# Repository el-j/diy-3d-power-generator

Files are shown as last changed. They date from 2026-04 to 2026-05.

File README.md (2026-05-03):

<p align="center">
  
  
  
  
</p>

<h1 align="center">🌬️ WindPower-3D</h1>
<h3 align="center">Open-Source Helix Helix Wind Generator — Fully 3D Printable</h3>

<p align="center">
  <strong>Parametric • Modular • AI-Orchestrated Design Bureau</strong><br/>
  Erzeuge deinen eigenen Strom mit einem 3D-gedruckten Windgenerator.<br/>
  <em>Generate your own power with a fully 3D-printed wind generator.</em>
</p>

---

## ⚡ Was ist WindPower-3D?

Ein **vollständig 3D-druckbarer Helix-Helix Windgenerator** mit integriertem XXL Axialfluss-Generator. Designed für den Bambu Lab P1S (256×256mm), aber kompatibel mit jedem FDM-Drucker.

### 🌟 Features

| Feature | Details |
|---|---|
| 🔄 **Modularer Turm** | Stapelbare Helix-Etagen mit 12-Zahn Vielzahn-Kupplung |
| ⚡ **XXL Generator** | 180mm Rotoren, 20-Pol, ovale Capsule-Spulen (40×26mm!) |
| 🏗️ **XXL Basis-Station** | 220mm Ø, Stacking-Deckel, Wartungsklappe, wasserdichte Bodenwanne |
| 🔧 **Profi-Werkzeuge** | Traversier-Wickelmaschine, Magnet-Puffer, Akkuschrauber-Aufsatz |
| 📐 **Parametrisches Design** | Alle Maße in JSON — ändere eine Zahl, alles passt sich an |
| 🤖 **AI Design Bureau** | 7 spezialisierte Agenten orchestrieren den Konstruktions-Workflow |
| 📋 **Lebende BOM** | Stückliste aktualisiert sich automatisch bei Änderungen |
| 📖 **Bauanleitungen** | Schritt-für-Schritt auf Deutsch mit Sicherheitshinweisen |

---

## 🏗️ System-Architektur

```mermaid
graph LR
    subgraph "🌬️ Wind Turbine"
        T["🗼 Helix Tower\n(Modular Stages)"]
        G["⚡ Generator\n(Axial Flux)"]
        B["🏗️ Base Station\n(Tree Mount)"]
    end
    
    subgraph "🤖 AI Design Bureau"
        O["🎛️ Orchestrator"]
        CAD["📐 CAD Engineer"]
        DRW["📏 Drawing Agent"]
        COD["🐍 FreeCAD Coder"]
        BOM["📋 BOM Manager"]
        BGD["📖 Build Guide"]
        QA["✅ QA Inspector"]
    end
    
    T --> G --> B
    O --> CAD --> DRW --> COD --> BOM --> BGD --> QA
    QA -->|PASS| O
```

---

## 📦 Baugruppen / Assemblies

### 🗼 Helix-Turm
Modulares Stecksystem mit 12-Zahn Vielzahn-Kupplung. Jede Etage: 2 Helix-Flügel (90° Twist), 1 Skelett-Verbinder, 1 Achsen-Plug.

### ⚡ XXL Axialfluss-Generator *(NEU v2!)*
Sandwich-Bauweise mit **180mm Rotoren** und **ovalen Capsule-Spulen** (40×26mm statt runde Ø14mm). 20 Neodym-Magnete auf R74mm Kreis für massives Drehmoment. Leichtbau-Skelettierung für weniger Filament und bessere Kühlung.

### 🏗️ XXL Basis-Station *(NEU v2!)*
**220mm Ø Gehäuse** mit 50mm Kegelrollenlager (real gemessen!), Stacking-Deckel, 3× Wand-Flansche, wasserdichte Bodenwanne und Elektronik-Wartungsklappe mit Backpack-Gehäuse.

### 🔧 Werkzeuge *(Erweitert v2!)*
- **Easy-Tool**: Akkuschrauber-Aufsatz zum schnellen Spulenwickeln
- **Komplex-Spooler**: Professionelle Traversier-Wickelmaschine (1:24 Zahnrad-Untersetzung, 4 Achsen, Skeleton-Basis)
- **Magnet-Puffer**: Magnetischer Drahtspanner mit T-Nut-Schiene und Filz-Bremse

---

## 🚀 Quick Start

### 1. Repository klonen
```bash
git clone https://github.com/YOUR_USERNAME/windpower-3d.git
cd windpower-3d
```

### 2. Stückliste prüfen
→ [`docs/bom/master_bom.md`](docs/bom/master_bom.md) — Alle Druck- und Kaufteile

### 3. Drucken
Öffne die STL-Dateien aus `exports/` in deinem Slicer. Empfohlenes Material: **PETG**.

### 4. Bauen
→ [`docs/build-guide/`](docs/build-guide/README.md) — Schritt-für-Schritt Anleitungen

### 5. FreeCAD Scripts laden (optional)
```python
# In FreeCAD Python Console einmal pasten:
exec(open("windpower-3d/freecad_loader.py").read())

# Dann jedes Script laden:
run("bigBasis/big_base_station")       # XXL Basis
run("bigBasis/big_base_generator")      # XXL Generator
run("Helix_Leaf+Connector")             # Turm
run("tools/komplexSPooler/Traversier-Basis & Skeleton")  # Wickelmaschine
```

### 6. Landing Page (TypeScript + Vite)
```bash
npm install
npm run typecheck
npm run dev
```

Production build:
```bash
npm run build
```
Das Ergebnis liegt in `dist/` und wird von GitHub Pages deployed.

### 7. GitHub Actions CI/CD (Static Hosting)
- CI Workflow: `.github/workflows/ci.yml` (führt `npm ci`, `npm run typecheck`, `npm run build` aus)
- Pages Deploy: `.github/workflows/deploy-pages.yml` (baut Artifact und deployed nach GitHub Pages)

Wichtig in GitHub Repo Settings:
- `Settings > Pages > Build and deployment` auf **GitHub Actions** setzen

---

## 📋 Stückliste (Kurzfassung)

| Kategorie | Menge (XXL, 3 Etagen) |
|---|:---:|
| 🖨️ Druckteile (Hauptanlage) | 29 Stück |
| 🖨️ Druckteile (Werkzeuge) | 3–22 Stück |
| 🔩 Einschmelzmuttern + Schrauben | ~52 Stück |
| 🧲 Neodym-Magnete (20×5×3mm) | **40 Stück** |
| ⚙️ Kegelrollenlager (29×50×15) | 1 Stück |
| 📏 Vierkant-Achse (10×10mm) | 1 Stück |
| 🔌 Kupferlackdraht (Ø0.5mm) | ~100m |
| 📦 Geschätztes Filament | ~1.5kg PETG |

→ [**Vollständige Stückliste**](docs/bom/master_bom.md)

---

## 🤖 AI Design Bureau

Dieses Projekt nutzt ein **KI-Agenten-System** inspiriert von [agency-agents](https://github.com/msitarzewski/agency-agents) und [claude-agent-blueprint](https://github.com/mongoistkeingemuese/claude-agent-blueprint).

### 7 Spezialisierte Agenten

| Agent | Aufgabe |
|---|---|
| 🎛️ **Orchestrator** | Pipeline-Management, Quality Gates, Retry-Logik |
| 📐 **CAD Engineer** | Parametrisches Design, Toleranzen, Druckbarkeit |
| 📏 **Drawing Agent** | 3-Ansichten-Zeichnungen (Front, Seite, Draufsicht) |
| 🐍 **FreeCAD Coder** | Python-Scripts, STL-Export, parametrische Geometrie |
| 📋 **BOM Manager** | Stückliste pflegen (JSON + Markdown) |
| 📖 **Build Guide Author** | Bauanleitungen auf Deutsch |
| ✅ **QA Inspector** | Vollständigkeits- und Konsistenzprüfung |

### Design-Pipeline

```
📐 Design → 📏 3-Ansichten → 🐍 FreeCAD Code → 📋 BOM Update → 📖 Bauanleitung → ✅ QA
     ↑                                                                                  │
     └──────────────────────── Feedback bei FAIL ──────────────────────────────────────┘
```

→ [**Architektur-Details**](docs/ARCHITECTURE.md)

---

## 📂 Projektstruktur

```
windpower-3d/
├── .agents/                    # 🤖 AI Agent System
│   ├── identities/             #    7 Agenten-Identitäten
│   ├── workflows/              #    Pipeline-Definitionen (JSON)
│   └── state.json              #    Orchestrator-Status
├── assemblies/                 # 📦 Baugruppen-Metadaten
│   ├── tower/                  #    🗼 Helix-Turm
│   ├── xl-base-station/        #    🏗️ XXL Basis-Station (AKTIV)
│   ├── xl-generator/           #    ⚡ XXL Generator (AKTIV)
│   ├── base-station/           #    📦 Legacy Kleine Basis
│   ├── generator/              #    📦 Legacy Generator
│   └── tools/                  #    🔧 4× Werkzeug-Sets
├── shared/                     # 🔗 Geteilte Ressourcen
│   ├── parameters.json         #    Zentrale Parameter-Registry (v2)
│   ├── freecad_utils.py        #    FreeCAD Utilities (inkl. Capsule!)
│   ├── materials.json          #    Material-Definitionen
│   └── fasteners.json          #    Verbindungselemente-Katalog
├── src/                        # 💻 FreeCAD Scripts
│   ├── bigBasis/               #    🏗️ XXL Basis + Generator
│   ├── smalBasis/              #    📦 Legacy (kleine Variante)
│   ├── tools/                  #    🔧 Werkzeuge
│   │   ├── komplexSPooler/     #       Traversier-Wickelmaschine
│   │   ├── firstSpooler/       #       Original-Wickler
│   │   ├── magnetPuffer/       #       Drahtspanner
│   │   └── easy_tool_*         #       Akkuschrauber-Aufsatz
│   └── Helix_Leaf+Connector.py #    🗼 Turm-Flügel
├── exports/                    # 📤 STL/3MF Exporte
├── freecad_loader.py           # 🚀 FreeCAD Script-Loader
├── docs/                       # 📚 Dokumentation
└── README.md                   #    ← Du bist hier
```

---

## 🛠️ Für Entwickler / FreeCAD Anpassungen

### Parameter ändern
Alle Maße sind zentral in [`shared/parameters.json`](shared/parameters.json) definiert:

```json
{
  "tower": {
    "blatt_radius": { "value": 66.0, "unit": "mm", "desc": "Helix-Blatt Radius" },
    "twist_winkel": { "value": 90.0, "unit": "deg", "desc": "Helix-Drehwinkel" }
  }
}
```

### Utility-Funktionen
[`shared/freecad_utils.py`](shared/freecad_utils.py) enthält alle gemeinsam genutzten Funktionen:
- `make_square_prism()` — Vierkant-Achsloch
- `make_vielzahn_prism()` — 12-Zahn Kupplung
- `make_capsule()` — Ovale Spulen-Form *(NEU v2)*
- `make_centered_box()` — Zentrierter Quader *(NEU v2)*
- `create_capsule_array()` — Kreisförmige Capsule-Muster *(NEU v2)*
- `create_circular_array()` — Kreisförmige Zylinder-Muster
- `load_parameters()` — Parameter aus JSON laden

---

## 🤝 Mitmachen / Contributing

Wir freuen uns über Beiträge! Siehe [`CONTRIBUTING.md`](CONTRIBUTING.md) für Details.

### Möglichkeiten
- 🐛 **Bugs melden** — Toleranzen, Passungsprobleme, Druckfehler
- 📐 **Design verbessern** — Neue Varianten, bessere Geometrie
- 📖 **Dokumentation** — Bauanleitungen, Übersetzungen
- 🤖 **Agenten** — Neue Fähigkeiten, bessere Learnings
- 🌍 **Übersetzungen** — Build-Guide in andere Sprachen

---

## 📜 Lizenz

MIT License — siehe [LICENSE](LICENSE)

---

<p align="center">
  <strong>🌬️ Erzeuge deinen eigenen Strom. Open Source. Druckbar. Modular.</strong><br/>
  <em>Made with ❤️ and a lot of PETG</em>
</p>

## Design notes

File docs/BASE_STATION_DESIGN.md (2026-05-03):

# XXL Base Station Design Reference

**Assembly**: XL Base Station v3.0  
**Source**: `src/base/helix_station.py`  
**Status**: ACTIVE

---

## Design Philosophy

The XXL Base Station solves a deceptively difficult mechanical problem: house a spinning shaft, two tapered roller bearings, a removable stator, a rectifier PCB, and wall-mounting hardware — all in a weatherproof enclosure that fits on a 256×256 mm print bed and does not look like an industrial accident bolted to a wall.

The guiding constraint was radical flatness. Earlier prototypes ran 120 mm tall. The current design is **68 mm** — a 43% reduction achieved by rethinking where the bearing stack sits relative to the stator and by eliminating an internal electronics bay in favour of a front-access service hatch. The result is a low-profile disc that presents minimal wind resistance on its mounting surface and routes cables cleanly through a single port at the base of the hatch.

Serviceability drove the second major decision: the stator must be removable without disturbing the rotor or bearings. Rewinding a stator coil after a fault is a routine maintenance event. Requiring a full teardown for that task is unacceptable in a field-mounted turbine. The solution is a precision U-form opening in the front face that lets the 9 mm stator slide in and out laterally — bearings stay in place, rotor stays in place, downtime is minutes rather than hours.

---

## Key Innovations

### Ultra-Flat 68 mm Profile

Outer diameter is 220 mm (R=110 mm) and total height is 68 mm. The inner chamber runs to R=96 mm, giving exactly 4 mm radial clearance to the rotor at R=92 mm. That clearance is a hard minimum — the rotor must never exceed R=95 mm. The flat profile lowers the aerodynamic shadow behind the mounting surface and simplifies cable exit geometry.

### U-Form Front Opening and Stator Slot

The front face has a full-height U-shaped cutout: 213 mm wide (±106.5 mm from centre), 68 mm tall. This is not a maintenance port — it is a first-class design feature. The stator slides through it horizontally to seat in a precision slot at Z=25.8–35.3 mm. Slot dimensions are 9.5 mm high (9 mm stator + 0.5 mm clearance) at a radius of 99.5 mm. The slot is cut as a 99.5 mm cylindrical channel intersected with a 200×140 mm rectangular box. The service hatch mirrors this with a 199×120 mm passage at the same Z height, so the stator path is clear even with the hatch fitted.

### 3D-Printed Bearing Cup Substitute

Rather than sourcing the metal outer race of the 32005 tapered roller bearing separately, the design includes a printed substitute cup (`Ersatz_Lagerschale_32005`): 50 mm outer diameter, 12 mm tall, with an internal taper from R=19.5 mm at the base to R=23 mm at the top. Only the cup is printed; the roller and cone assembly are standard metal hardware. This removes a sourcing dependency while keeping the load-bearing contact surfaces metal.

---

## Part Reference

| Part ID | FreeCAD Name | Function | Qty |
|---|---|---|---|
| XL-HOUS-01 | `Basis_Gehaeuse_XXL` | Main housing, R=110 mm, H=68 mm | 1 |
| XL-DECK-01 | `Stacking_Lager_Deckel_FLACH` | Top lid with bearing pocket | 1 |
| XL-FLNSH-01 | `Wand_Flansch` | Wall mounting flange | 3 |
| XL-KLAP-01 | `Elektronik_Wartungs_Klappe` | Front service hatch | 1 |
| XL-BODEN-01 | `Wartungsklappen_Boden` | Detachable hatch floor | 1 |
| — | `Ersatz_Lagerschale_32005` | Printed bearing cup substitute | 1 |

### XL-HOUS-01 — Main Housing

Outer radius 110 mm, height 68 mm, inner chamber R=96 mm. U-form opening 213 mm wide × 68 mm tall. Stator slot at Z=25.8 mm, height 9.5 mm, radius 99.5 mm.

### XL-DECK-01 — Stacking Lid

Outer radius 110 mm, height 18 mm. Bearing pocket 50.2 mm diameter × 15 mm deep (32005 bearing). Upper guide lip: R=85–95.5 mm, 6 mm tall, for centering. Six 20 mm weight-relief holes at R=70 mm. Twelve M3 fasteners at R=104 mm, 30° spacing with 15° offset.

### XL-FLNSH-01 — Wall Flange (×3)

L-shaped bracket: vertical face 40×68 mm × 6 mm thick; horizontal arm 50×40 mm × 6 mm thick. Triangular gussets 4.0 mm reinforce the joint. Wall screws: 4× M3 at Z=15 mm and Z=53 mm, Y=±12 mm. Equipment mounting: 2× M6 on arm at Y=±10 mm, 38 mm deep.

### XL-KLAP-01 — Service Hatch

U-shaped, matching 213×150 mm front opening exactly. Wall thickness 6 mm roof and sides. Interior cavity 201×145 mm for PCB and wiring. Four PCB standoffs (4 mm OD, 5 mm tall) at (±25 mm, Z=20 mm) and (±25 mm, Z=50 mm). Cable port 10 mm diameter at X=0, Y=−135 mm, Z=10 mm. Two M3 lock screws at Y=−20 mm, Z=34 mm (left and right faces). Stator slot passage: 199×120 mm at Z=25.8 mm.

### XL-BODEN-01 — Hatch Floor

6 mm thick plate with R=96 mm rotor clearance cutout. Four corner tabs 12×12×8 mm with M3 counterbores for tool-free removal.

---

## Hardware BOM

| Item | Spec | Qty | Notes |
|---|---|---|---|
| Tapered roller bearing | 32005 — 29×50×15 mm | 1 | Dimensions real-measured, not datasheet |
| Hex socket cap screw | M3×10 | 12 | Lid-to-housing |
| Hex socket cap screw | M3×8 | 8 | Hatch lock + floor tabs |
| Hex socket cap screw | M6×40 | 6 | Wall flange equipment bolts (2× per flange) |
| Wood / masonry screw | M4 or M5 | 12 | Wall mounting (4× per flange) |
| Rectifier PCB | — | 1 | Mounts on hatch standoffs |
| Cable gland / sleeve | 10 mm ID | 1 | Hatch cable port |

---

## Print Settings

| Part | Material | Nozzle | Infill | Notes |
|---|---|---|---|---|
| XL-HOUS-01 | PLA-CF | 0.6 mm | 30% | Large print — check bed orientation |
| XL-DECK-01 | PLA-CF | 0.4 mm | 40% | Bearing pocket requires precision |
| XL-FLNSH-01 | PLA-CF | 0.6 mm | 60% | Structural — print all 3 |
| XL-KLAP-01 | PETG | 0.6 mm | 25% | Service part, slight flex acceptable |
| XL-BODEN-01 | PETG | 0.6 mm | 25% | Detachable, does not carry load |

All parts fit within the 256×256×256 mm Bambu P1S envelope. XL-HOUS-01 at 220 mm diameter prints diagonally on the bed. Orient so the U-form opening faces up to avoid internal support in the stator slot cavity.

---

## Critical Dimensions Summary

| Parameter | Value | Constraint |
|---|---|---|
| Outer diameter | 220 mm (R=110) | Print bed diagonal |
| Total height | 68 mm | Flat-profile target |
| Inner chamber | R=96 mm | 4 mm clearance to rotor R=92 |
| U-opening width | 213 mm | Stator insertion path |
| Stator slot Z | 25.8–35.3 mm | Synchronized with hatch |
| Stator slot height | 9.5 mm | 9 mm stator + 0.5 mm clearance |
| Bearing seat | Ø50.2 mm × 15 mm | 32005 press fit |
| Rotor hard limit | R=95 mm max | Geometry enforced in parameters.json |

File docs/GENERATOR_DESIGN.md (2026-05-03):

# Aero-Fan Generator — Design Document

**Project**: WindPower-3D | **Assembly**: XL Generator v3.0 | **Status**: Active

---

## Overview

The Aero-Fan generator is a 3D-printable **axial-flux permanent magnet generator (AFPMG)** designed for small-scale wind power applications. It is built around a TORUS-NS dual-rotor topology and introduces two notable mechanical innovations: a dual-function fan/magnet rotor and a unified spline coupling system that eliminates tool dependencies during blade changes.

---

## Key Innovations

> **Dual-function rotor**: The rotor plates (`XLG-ROT-01`, `XLG-ROT-02`) carry both the permanent magnets and 11 aerodynamic fan blades in a single printed part. As the rotor spins, it simultaneously generates electricity through rotating magnetic fields and forces cooling airflow across the stator coils via centrifugal action — removing the need for a separate cooling fan while keeping the assembly compact.

> **Capsule coils**: The stator (`XLG-STAT-01`) uses oval (stadium-shaped) coil pockets rather than round ones, aligning coil geometry with the arc of the magnet circle (R=74 mm). This reduces end-winding waste and improves copper fill in the radial space available.

> **Unified Vielzahn spline**: Every rotary connection in the system uses the same 12-tooth spline profile — tower blades, generator rotor, and tools all share `r_out=9.0 mm`, `r_in=7.8 mm`, 12 teeth. This gives 30° indexing resolution and enables tool-free hot-swap of components.

---

## Design Philosophy

The generator is sized to fit a 256×256×256 mm Bambu P1S print bed and targets a reliable 10–50 W output range at low wind speeds (6–12 m/s). Every dimensional choice reflects a compromise between magnetic performance and printability:

- **Axial-flux topology** keeps the generator thin and flat — ideal for integration into a vertical tower without adding height.
- **20-pole, 12-coil configuration** (TORUS-NS) gives a 3-phase output at usable frequencies even at low RPM. At 100 RPM the electrical frequency is approximately 33 Hz (`100 RPM × 20 poles / 60`).
- **N52 neodymium magnets** (20×5×3 mm) were chosen as a standard stocked size. The magnet circle radius of R=74 mm also doubles as the rotor fastening radius, reducing the number of unique drill positions.
- **4 mm rotor-to-chamber clearance** (`rotor R=92 mm`, inner chamber `R=96 mm`) is maintained as a hard constraint — the rotor must never exceed R=95 mm.
- **PLA-CF for structural parts**, PETG for the stator: carbon-fiber PLA provides stiffness at the rotor and bearing interfaces; PETG tolerates the heat generated in the stator coils.

---

## How It Works

**Faraday's law** states that a changing magnetic flux through a coil induces a voltage proportional to the rate of change. In an axial-flux machine, the magnets are oriented with their poles facing axially (parallel to the shaft), and the coils sit in a flat disk (the stator) between two rotor plates. As each magnet passes over a coil, the flux through that coil changes sign (N→S polarity), inducing an AC voltage.

The dual-rotor arrangement (one rotor plate above and one below the stator) doubles the flux linkage per coil compared to a single-sided design, increasing output for the same rotor diameter.

The 12 stator coils are wired in a **3-phase star (Y) configuration** with 4 coils per phase. At 100 RPM with 20 pole pairs the phase voltage frequency is `f = n × p / 60 = 100 × 10 / 60 ≈ 16.7 Hz` electrical. The output is rectified to DC for battery charging or direct LED load testing. Design efficiency target is η=72%.

---

## Generator Topology

| Parameter | Value |
|---|---|
| Type | Axial-flux, dual-rotor, single-stator (TORUS-NS) |
| Poles | 20 (10 pole pairs) |
| Coils | 12 capsule-shaped (4 per phase, 3-phase AC) |
| Magnet spec | 20×5×3 mm N52 neodymium |
| Magnet circle radius | R=74 mm (= rotor screw radius) |
| Design output | 10–50 W at 6–12 m/s |
| Efficiency target | η=72% |

---

## The Aero-Fan Rotor (`XLG-ROT-01` / `XLG-ROT-02`)

| Parameter | Value |
|---|---|
| Total radius | 92 mm (Ø184 mm) |
| Hub radius | 16.5 mm |
| Outer structural rim | R=92–102 mm |
| Fan blades | 11 aerodynamic blades (lofted profile) |
| Inner blade profile | R=11.5 mm, chord=22 mm, pitch angle=75° |
| Outer blade profile | R=107 mm, chord=32 mm, pitch angle=50°, sweep=45° |
| Weight-relief pockets | 15 capsule pockets (18×10 mm), avoiding 5 screw positions |
| Fastening | 5× M3 heat-set inserts at R=74 mm: 10°, 82°, 154°, 226°, 298° |
| Magnet lip | 0.6 mm retaining edge per pocket |

The **backplates** (`XLG-BP-01` / `XLG-BP-02`) are thin structural rings (R=62–86 mm, 4 mm height) with synchronized magnet pockets that close the magnet retention from the opposite side.

---

## The Stator (`XLG-STAT-01` / `XLG-STAT-02`)

| Parameter | Value |
|---|---|
| Outer radius | 99 mm |
| Thickness | 9 mm |
| Base bore | R=16 mm (shaft clearance) |
| Coil pocket (outer) | 40.4×26.4 mm (0.4 mm clearance) |
| Coil winding core | 22×8 mm |
| Coil depth | 6 mm |
| Coil count | 12 at R=74 mm |
| Winding | 120–150 turns, 0.5 mm enameled copper wire |
| Weight-relief holes | 6× at R=35 mm |
| Cable channel | Ring channel R=82–88 mm at Z=6.5 mm + radial handle channel |

The stator lid (`XLG-STAT-02`) is a thin cover ring (R=50.5–95.5 mm, 1.5 mm thick) with cutouts matching the coil pockets, allowing wire routing after winding.

---

## Assembly Stack (bottom to top)

| Z position | Part | Part ID |
|---|---|---|
| −80 mm | Bearing reducer (bottom) | `XLG-REDUZ-01` |
| −60 mm | Bearing clamp (bottom, rotated 180°) | `XLG-CLAMP-02` |
| −50 mm | Rotor stack clamp (30 mm plug) | `XLG-CLAMP-01` |
| −30 mm | Backplate (bottom) | `XLG-BP-01` |
| −20 mm | Aero-Fan Rotor (bottom) | `XLG-ROT-01` |
| −5 mm | Stator spacer 10 mm | `XLG-SPACER-01` |
| 0–9 mm | Stator housing | `XLG-STAT-01` |
| 10–25 mm | Stator lid (inset) | `XLG-STAT-02` |
| 35 mm | Aero-Fan Rotor (top) | `XLG-ROT-02` |
| 50 mm | Backplate (top) | `XLG-BP-02` |
| 90 mm | Bearing clamp (top) | `XLG-CLAMP-03` |
| 110 mm | Bearing reducer (top, rotated 180°) | `XLG-REDUZ-02` |

---

## Bearing System

- **Type**: Tapered roller bearing 32005 — 29×50×15 mm (real measured dimensions)
- **Press fit**: 0.15 mm interference fit for shaft coupling
- **Bearing reducer** (`XLG-REDUZ-01` / `XLG-REDUZ-02`): Conical adapter tapering 27.5→29.3 mm over 2 mm taper length, with a 34 mm collar

---

## Vielzahn Coupling System

All rotary connections throughout the system (tower blades, generator rotor, tools) share a single unified spline profile to avoid mismatched parts:

| Parameter | Value |
|---|---|
| Teeth | 12 (30° indexing) |
| Outer radius | 9.0 mm |
| Inner radius | 7.8 mm |
| Orientation offset | +15° (aligns teeth to square shaft corners) |
| Square shaft bore | 10×10 mm + 0.5 mm tolerance |

---

## Print Settings

| Part | Material | Nozzle | Infill | Notes |
|---|---|---|---|---|
| `XLG-ROT-01` / `XLG-ROT-02` | PLA-CF | 0.6 mm | 40% | Carbon fiber for stiffness |
| `XLG-STAT-01` | PETG | 0.6 mm | 30% | Heat-resistant for coil area |
| `XLG-BP-01` / `XLG-BP-02` | PLA-CF | 0.6 mm | 40% | Thin ring, needs strength |
| `XLG-CLAMP-*` | PLA-CF | 0.4 mm | 100% | Bearing contact surface |
| `XLG-REDUZ-*` | PLA-CF | 0.4 mm | 100% | Press-fit precision required |

---

## Estimated Electrical Output

| Condition | Value |
|---|---|
| Electrical frequency at 100 RPM | ~16.7 Hz (100 × 10 pole pairs / 60) |
| Design wind speed range | 6–12 m/s |
| Design output range | 10–50 W |
| Output type | 3-phase AC → rectified DC |
| Use cases | Battery charging, LED load testing |
| Efficiency target | η=72% |

---

*Source script*: `src/generator/helix_generator.py` | *Parameters*: `shared/parameters.json` § `xl_generator`

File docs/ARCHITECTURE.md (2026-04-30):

# docs/ARCHITECTURE.md
# 🏗️ Architecture — WindPower-3D Design Bureau

## System Overview

This project uses an **AI-agent-orchestrated design pipeline** to manage the full lifecycle of 3D-printed components: from parametric design through technical drawings, FreeCAD code, BOM management, and build instructions.

### Design Patterns Used

| Pattern | Source | Application |
|---|---|---|
| Identity-driven agents | [agency-agents](https://github.com/msitarzewski/agency-agents) | Each agent has personality, mission, deliverables, learnings |
| Task pipeline | [claude-agent-blueprint](https://github.com/mongoistkeingemuese/claude-agent-blueprint) | Phased workflow with quality gates |
| Skill routing | claude-agent-blueprint | Domain specialists triggered by task type |
| State machine | claude-agent-blueprint | `state.json` tracks queue, active, history |
| Self-evolution | Both repos | Agents accumulate learnings over time |

## Pipeline Architecture

```
┌─────────────────────────────────────────────────────────────┐
│                   🎛️ ORCHESTRATOR                          │
│  Reads: state.json    Writes: state.json                    │
│  Controls: Phase progression, retries, quality gates        │
└─────────────┬───────────────────────────────────────────────┘
              │
    ┌─────────▼──────────┐
    │  P1: CAD Engineer   │ → component.json (params, tolerances)
    ├─────────▼──────────┤
    │  P2: Drawing Agent  │ → front.svg, side.svg, top.svg
    ├─────────▼──────────┤
    │  P3: FreeCAD Coder  │ → component.py, exports/*.stl
    ├─────────▼──────────┤
    │  P4: BOM Manager    │ → assembly_bom.md, master_bom.json
    ├─────────▼──────────┤
    │  P5: Build Guide    │ → build-guide/*.md
    ├─────────▼──────────┤
    │  P6: QA Inspector   │ → qa_report (PASS/NEEDS_WORK)
    └────────────────────┘
              │
         PASS ↓ FAIL → Route back to failing phase
```

## Data Flow

```
shared/parameters.json ──────────────┐
shared/materials.json ───────────────┤
shared/fasteners.json ───────────────┤
                                     ▼
                            ┌─────────────────┐
                            │  Component JSON  │
                            │  (per component) │
                            └────────┬────────┘
                                     │
                    ┌────────────────┼────────────────┐
                    ▼                ▼                ▼
              ┌──────────┐   ┌────────────┐   ┌──────────┐
              │ Drawings  │   │ FreeCAD.py │   │   BOM    │
              │  (SVG)    │   │  + STL     │   │ (MD+JSON)│
              └──────────┘   └────────────┘   └──────────┘
```

## Directory Conventions

| Path | Purpose |
|---|---|
| `.agents/identities/` | Agent identity files (personality + rules) |
| `.agents/workflows/` | Pipeline definitions (JSON) |
| `.agents/state.json` | Runtime state (queue, progress) |
| `assemblies/<name>/` | Assembly with components subdirectories |
| `shared/` | Global parameters, utilities, catalogs |
| `docs/bom/` | Bill of Materials (master + per-assembly) |
| `docs/build-guide/` | Step-by-step assembly instructions (DE) |
| `exports/` | STL/3MF build outputs |
| `src/` | FreeCAD Python scripts (bigBasis = active, smalBasis = legacy) |
| `src/bigBasis/` | XXL Generator + XXL Base Station (v2.x, ACTIVE) |
| `src/smalBasis/` | Small 10/20-pole generator + base station (LEGACY) |
| `src/tools/` | Winding machines and manufacturing tools |
| `src/tools/komplexSPooler/example.aufbau.py` | Virtual assembly (visual reference, not a printed part) |
| `exports/generator/` | Latest XXL generator STLs |
| `exports/xl_basis/` | Latest XXL base station STLs |

## Active Assembly Versions (2026-04-30)

| Assembly | Version | Source |
|---|---|---|
| xl-generator | **2.1.0** | `src/bigBasis/big_base_generator.py` |
| xl-base-station | 2.0.0 | `src/bigBasis/big_base_station.py` |
| tools | **2.1.0** | `src/tools/komplexSPooler/` |
| tower | 1.x | `src/Helix_Leaf+Connector.py` |

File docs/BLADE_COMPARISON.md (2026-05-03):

# VAWT Blade Comparison — WindPower-3D

> Five interchangeable vertical-axis wind turbine blade designs for the Helix Wind-Generator tower stack.
> All designs share the unified Vielzahn spline coupling and print within the Bambu P1S 256 mm bed.

---

## Overview: Hot-Swappable Blade Assemblies

The WindPower-3D tower is built as a stack of identical stages. Each stage is 240 mm tall, carries one blade assembly, and connects to the next via the unified Vielzahn (multi-tooth spline) coupling. Because the coupling geometry is identical across all five blade types, a complete blade swap requires only removing the connector cap, sliding out the old blade set, and pressing in the new one — no shaft modification, no re-drilling, no re-wiring.

This modularity lets you:
- Match blade aerodynamics to your local wind regime without rebuilding the tower
- Mix blade types across stages (e.g., a Savonius stage at the bottom for low-wind start-up, Gorlov stages above for efficiency)
- Test and compare blade types on the same physical tower over time

All five designs described in this document are parametrically defined in `shared/parameters.json` under `tower` and `tower_variants`, and are generated by scripts in `src/leaf/`.

---

## Unified Coupling System

Every blade design uses the same mechanical interface. These dimensions are locked and must never be changed independently per blade type — they are defined once in `global` and `tower` sections of `shared/parameters.json`.

| Parameter | Value | Source key |
|---|---|---|
| Spline profile | Vielzahn (multi-tooth) | `global.vielzahn_zaehne` |
| Number of teeth | 12 | `global.vielzahn_zaehne` |
| Indexing step | 30° per tooth | derived |
| Outer radius | 9.0 mm | `global.vielzahn_r_out` |
| Inner radius | 7.8 mm | `global.vielzahn_r_in` |
| Orientation offset | +15° (aligns teeth to shaft corners) | hardcoded in `make_vielzahn_prism()` |
| Square shaft | 10 × 10 mm + 0.5 mm tolerance | `global.achse_kantenlaenge` + `global.toleranz` |
| Stage height | 240 mm | `tower.hohe` |
| Blade radius | 66 mm (132 mm rotor diameter) | `tower.blatt_radius` |
| Connector cap height | 8 mm | `tower.kappen_dicke` |
| Groove depth (snap fit) | 3 mm | `tower.rillen_tiefe` |

The +15° orientation offset is critical: it rotates the spline teeth so that the thick tooth flanks land exactly on the 45° diagonal corners of the square shaft hole, distributing torque evenly and preventing stress concentrations.

---

## Blade Designs

### 1. Helix (Savonius Coreless Helical) — `TWR-LEAF-01`

The default blade of this project. A single blade surface twisted 90° from bottom to top using a lofted helix through 60 interpolation steps. Because the blade is never absent from any azimuth angle (the 90° twist gives continuous coverage), a single blade per stage suffices.

| Specification | Value |
|---|---|
| Principle | Hybrid drag/lift |
| Blades per stage | 1 |
| Wall thickness | 2.4 mm |
| Twist | 90° (bottom to top) |
| Loft steps | 60 |
| Tip Speed Ratio (TSR) | 1.0–1.5 |
| Power coefficient (Cp) | ~18% |
| Self-starting | Yes |

**Key parts:** `Coreless_Helix_Fluegel`, `Mittel_Verbinder_Skelett_FLACH`, `Zwischen_Vielzahn_Plug`, `Start_Scheibe_FLACH`

**Best for:** Variable or gusty wind, urban rooftops, sites with frequent wind direction changes. The lowest cut-in wind speed of the lift-assisting designs.

**Print settings:** PETG, 0.6 mm nozzle, 20% infill, supports required for overhanging loft surface.

---

### 2. Savonius Straight — `TWR-STR-01`

The classical Savonius bucket rotor. Two opposing semi-circular cups extruded vertically with no twist. The advancing cup captures drag force; the retreating cup is partially sheltered by the advancing one. Simple geometry, maximum printability, highest starting torque.

| Specification | Value |
|---|---|
| Principle | Pure drag (Savonius bucket) |
| Blades per stage | 2 (180° opposing) |
| Wall thickness | 2.4 mm |
| S-offset | 12 mm |
| Twist | 0° |
| TSR | ~0.8–1.0 |
| Cp | ~14% |
| Self-starting | Yes — highest starting torque of all five types |

**Best for:** Very low wind speeds (below 3 m/s cut-in), mechanical loads requiring high torque (water pumps, grain mills), sites where turbine must never stall.

**Print settings:** PETG, 0.6 mm nozzle, 20% infill, no supports needed (straight extrusion).

---

### 3. Darrieus H-Rotor — `TWR-DAR-01`

A straight-bladed Darrieus rotor (H-frame). Three symmetric airfoil blades at 120° spacing generate lift as they orbit the shaft. The airfoil cross-section approximates a NACA profile: a 4 mm half-cylinder nose, a 2.2 mm half-cylinder tail, and a 15.4 × 4 mm body offset 1.2 mm toward the leading edge. Two horizontal struts per blade at 15% and 85% height carry the blade loads to the central hub.

| Specification | Value |
|---|---|
| Principle | Pure lift (airfoil) |
| Blades per stage | 3 (120° spacing) |
| Chord | 20 mm |
| Thickness | 4 mm |
| Strut diameter | 4 mm |
| Hub radius | 12 mm |
| Twist | 0° (straight H-frame) |
| TSR | 3.0–4.0 |
| Cp | ~28% |
| Self-starting | Poor — needs initial push or motor-start assist |

**Best for:** Sites with consistent moderate-to-high wind (above 5 m/s), applications where efficiency is the primary goal and self-starting is not required.

**Print settings:** PLA-CF, 0.4 mm nozzle (required for airfoil accuracy), 100% infill on struts, 40% infill on blade body.

---

### 4. Gorlov Helical — `TWR-GOR-01`

A helical Darrieus rotor: the same lift-generating airfoil principle as the H-rotor, but with three blades each twisted 120° over the full stage height. The helical offset means that at any instant, at least one blade is in a favorable lift position — torque ripple is dramatically reduced compared to the straight Darrieus, and the rotor is self-starting due to the asymmetric torque distribution at rest.

| Specification | Value |
|---|---|
| Principle | Lift-drag hybrid (helical Darrieus) |
| Blades per stage | 3 (120° base spacing) |
| Chord | 16 mm |
| Thickness | 3.4 mm (biconvex symmetric) |
| Twist | 120° per stage height |
| Loft steps | 48 |
| TSR | 2.0–3.0 |
| Cp | ~32% |
| Self-starting | Yes |

**Best for:** Consistent wind regimes, applications requiring maximum efficiency and smooth power delivery. The highest Cp of all five designs.

**Print settings:** CF-Nylon or PLA-CF, 0.4 mm nozzle, 40% infill, no supports (helical loft is self-supporting).

---

### 5. Lenz2 — `TWR-LEN-01`

An asymmetric cup rotor that combines Savonius drag capture with leading-edge vortex lift. The outer cup spans 210° of arc; the inner surface is the same arc scaled to 62% and offset inward by the wall thickness. This geometry creates a deep cup that captures the direct drag impulse while the sharp leading edge generates a vortex that produces additional lift — a similar mechanism to delta-wing aerodynamics at high angle of attack.

| Specification | Value |
|---|---|
| Principle | Drag with vortex-assist lift (Lenz2/Magnus hybrid) |
| Blades per stage | 3 (120° spacing) |
| Cup arc | 210° |
| Inner surface scale | 0.62× |
| Wall thickness | 2.4 mm |
| Twist | 0° |
| TSR | 1.2–1.8 |
| Cp | ~22% |
| Self-starting | Yes |

**Best for:** Urban or suburban environments with turbulent, direction-changing wind. Better efficiency than pure Savonius while retaining reliable self-starting. A practical compromise between the Helix and the Gorlov.

**Print settings:** PLA-CF, 0.6 mm nozzle, 30–40% infill, no supports needed.

---

## Master Comparison Table

| Type | Principle | Blades/Stage | Twist | TSR | Cp | Self-Starting | Best Wind Condition | Print Difficulty |
|---|---|:---:|:---:|:---:|:---:|:---:|---|:---:|
| Helix (TWR-LEAF-01) | Drag/lift hybrid | 1 | 90° | 1.0–1.5 | ~18% | Yes | Variable/gusty | Medium |
| Savonius Straight (TWR-STR-01) | Pure drag | 2 | 0° | 0.8–1.0 | ~14% | Yes (best torque) | Very low wind | Easy |
| Darrieus H-Rotor (TWR-DAR-01) | Pure lift | 3 | 0° | 3.0–4.0 | ~28% | No | Consistent moderate-high | Hard |
| Gorlov Helical (TWR-GOR-01) | Lift/drag hybrid | 3 | 120° | 2.0–3.0 | ~32% | Yes | Consistent, any speed | Hard |
| Lenz2 (TWR-LEN-01) | Drag + vortex lift | 3 | 0° | 1.2–1.8 | ~22% | Yes | Urban/turbulent | Medium |

---

## Selection Guide

Choose your blade type based on your highest-priority constraint:

**Maximum starting torque / mechanical load (pump, mill):**
Use **Savonius Straight**. Nothing starts more reliably or delivers more torque at low RPM. Accept the lower Cp as the cost of robustness.

**Lowest possible cut-in wind speed:**
Use **Helix** or **Savonius Straight**. Both self-start below 2 m/s in light breeze. The Helix adds modest lift assist above that threshold.

**Maximum electrical efficiency:**
Use **Gorlov Helical**. At ~32% Cp it approaches the practical ceiling for a VAWT, and unlike the Darrieus H-Rotor it self-starts reliably.

**Urban or rooftop installation (turbulent, gusty, direction-variable wind):**
Use **Helix** or **Lenz2**. The Helix handles direction changes best; the Lenz2 offers better average Cp in turbulent conditions where the wind maintains a rough dominant direction.

**Consistent moderate-to-high wind, efficiency critical, motor-start available:**
Use **Darrieus H-Rotor**. Its pure lift principle gives the most predictable power curve once above cut-in speed, and the straight extrusion keeps print tolerances tight on the airfoil.

**General-purpose / unknown site:**
Start with the **Helix** (default assembly). It is the design this project was built around, has the most tested connector geometry, and performs acceptably across the widest range of conditions.

---

## Aerodynamic Concepts

### Tip Speed Ratio (TSR)

TSR is the ratio of blade tip velocity to wind velocity: `TSR = (blade tip speed) / (wind speed)`. A TSR of 1.0 means the tip moves at the same speed as the incoming wind. Drag-based rotors operate efficiently at low TSR (0.8–1.5) because the drag force diminishes as the blade accelerates toward wind speed. Lift-based rotors need the blade to move faster than the wind (TSR 2–4) to maintain a favorable angle of attack on the airfoil. TSR directly determines whether a given rotor design is well-matched to a generator's load torque curve.

### Power Coefficient (Cp)

Cp is the fraction of available wind power that the rotor converts to shaft power: `Cp = P_shaft / P_wind`. The Betz limit (59.3%) is the theoretical maximum for any wind turbine — no rotor can extract more than this fraction of the kinetic energy from a stream of air without bringing it to a complete stop. In practice, VAWTs reach 20–35% Cp due to tip losses, blade wake interference, and mechanical friction. Horizontal-axis turbines can reach ~45% Cp but are not self-starting and require active yaw control.

### Self-Starting

A rotor is self-starting if it can accelerate from rest to operational speed without external assistance. Drag-based rotors (Savonius, Lenz2) self-start because drag force acts on the stationary blade immediately — the cup facing into the wind experiences higher drag than the cup facing away. Lift-based rotors (Darrieus) do not self-start easily: airfoil lift requires a minimum angle of attack relative to the apparent wind, which only develops once the blade is already moving at a significant fraction of the target TSR. Helical variants (Gorlov) partially solve this by ensuring that at least one blade always has an asymmetric position that creates a net torque at rest.

### Torque Ripple and Helical Designs

A straight-bladed rotor generates pulsing torque: as each blade passes through the high-drag/high-lift azimuth angle, shaft torque spikes, then drops as the blade moves to the unfavorable position. With 2 blades, torque ripple frequency is `2 × RPM`; with 3 blades, `3 × RPM`. This ripple stresses the drivetrain, creates vibration, and causes voltage ripple in the generator output. Helical designs (Helix with 90° twist, Gorlov with 120° twist) spread the blade's contribution across all azimuth angles simultaneously: the bottom of the blade is always at a different position than the top. The result is a nearly constant torque delivery regardless of RPM — quieter operation, lower bearing stress, and cleaner electrical output with less rectification filtering required.

---

## Glossary

| Term | Definition |
|---|---|
| VAWT | Vertical-Axis Wind Turbine — shaft is vertical, works regardless of wind direction |
| TSR | Tip Speed Ratio — blade tip velocity divided by wind velocity |
| Cp | Power coefficient — fraction of wind power extracted by the rotor |
| Betz limit | 59.3% — theoretical maximum Cp for any wind turbine |
| Savonius | Drag-type VAWT using opposing cups; high torque, low efficiency |
| Darrieus | Lift-type VAWT using airfoils; high efficiency, poor self-starting |
| Gorlov | Helical Darrieus variant; smoothed torque, self-starting |
| Lenz2 | Asymmetric cup with vortex-lift assist; intermediate drag/lift |
| Vielzahn | Multi-tooth spline coupling used throughout this project |
| TWR-LEAF-01 | Part ID for the Helix blade assembly |
| TWR-STR-01 | Part ID for the Savonius Straight blade assembly |
| TWR-DAR-01 | Part ID for the Darrieus H-Rotor blade assembly |
| TWR-GOR-01 | Part ID for the Gorlov Helical blade assembly |
| TWR-LEN-01 | Part ID for the Lenz2 blade assembly |
| Torque ripple | Cyclic variation in shaft torque as blades rotate through their azimuth positions |
| Cut-in speed | Minimum wind speed at which the rotor begins generating useful power |
| Loft | FreeCAD operation that interpolates a 3D surface between a series of 2D cross-sections |

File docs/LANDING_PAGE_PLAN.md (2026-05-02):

# 🌬️ Interactive Landing Page — Full Design & Orchestration Plan

> Target: GitHub Pages · Technology: Three.js · Goal: Industry-grade immersive 3D experience
> Audience: Makers, engineers, open-source energy enthusiasts worldwide

---

## Vision Statement

A **single-page experience** where the Helix Wind Generator comes to life in the browser. Wind blows, the helix spins, the user builds their own tower and understands how much energy they can harvest. Not a documentation page — a **playground**.

---

## 1. Architecture Overview

```
/docs (GitHub Pages root)
├── index.html              ← single HTML shell
├── main.js                 ← scene orchestration entry point
├── style.css               ← minimal base styles
├── assets/
│   ├── models/
│   │   ├── helix_leaf.glb          ← one blade stage
│   │   ├── connector.glb           ← stage connector
│   │   ├── generator.glb           ← generator assembly
│   │   ├── base_station.glb        ← housing
│   │   └── vielzahn_plug.glb       ← plug detail
│   ├── textures/
│   │   ├── petg_normal.jpg         ← FDM surface normal map
│   │   ├── carbon_fiber.jpg        ← PLA-CF visual
│   │   └── hdri_sky.hdr            ← environment lighting
│   └── data/
│       └── wind_power_curve.json   ← Cp/wind-speed data
├── src/
│   ├── scene/
│   │   ├── SceneManager.js         ← Three.js setup, renderer, camera
│   │   ├── Lighting.js             ← HDRI + directional lights
│   │   └── PostProcessing.js       ← bloom, chromatic aberration
│   ├── assembly/
│   │   ├── HelixTower.js           ← procedural tower builder
│   │   ├── GeneratorStack.js       ← generator assembly
│   │   └── BaseStation.js          ← base housing
│   ├── simulation/
│   │   ├── WindSystem.js           ← particle wind field
│   │   ├── RotationPhysics.js      ← RPM from wind speed
│   │   └── PowerCalculator.js      ← energy output math
│   ├── ui/
│   │   ├── Controls.js             ← floating UI panel
│   │   ├── Tooltip.js              ← part hover labels
│   │   └── EnergyDisplay.js        ← live watt/kWh readout
│   └── export/
│       └── STLExportLink.js        ← deep links to STL files
```

---

## 2. 3D Scene Design

### 2.1 Camera & Environment

- **Camera**: PerspectiveCamera, FOV 45°, near 0.1 / far 500
- **Default view**: Slight angle (15° tilt, 30° yaw) — shows blades AND generator
- **Controls**: OrbitControls with damping (0.05) — smooth, weighted inertia
- **Auto-rotate**: Slow 0.2°/s when idle > 5s, stops on any interaction
- **Environment**: HDR sky — sunny day, light clouds, subtle blue atmosphere
- **Ground plane**: Faint circular concrete pad under base station, dissolves at distance
- **Depth of field**: Subtle — background slightly out of focus (BokehPass)

### 2.2 Materials

All parts use PBR materials matching printed appearance:

| Part group | Material preset | Properties |
|---|---|---|
| Helix blades (TWR-LEAF) | Translucent PETG, light teal | roughness 0.3, metalness 0.0, transmission 0.15 |
| Connectors, plugs | Matte grey PETG | roughness 0.7, metalness 0.05 |
| Rotors, backplates | Carbon-fiber PLA-CF | roughness 0.4, metalness 0.2, normal map |
| Stator | White/cream PETG | roughness 0.65, metalness 0.0 |
| Base housing | Dark grey PETG | roughness 0.6, metalness 0.05 |
| Metal fasteners | Silver steel | roughness 0.25, metalness 0.9 |
| Generator wiring | Copper lacquered | roughness 0.3, metalness 0.8, emissive orange glow at power |

### 2.3 Animation System

**LayerAnimation** — each part has 3 states:
1. `assembled` — final position
2. `exploded` — radially separated along axis (toggle with E key or UI button)
3. `highlighted` — scale 1.05, outline glow, tooltip visible

**RotationLoop** (always running when wind > 0):
- Driven by `RotationPhysics.getRPM(windSpeed)`
- Helix stages counter-rotate in pairs if tower is >2 stages (authentic VAWT behavior)
- Generator rotors rotate at same RPM
- Smooth acceleration/deceleration curve (exponential ease, τ=1.5s)

---

## 3. Wind Simulation System

### 3.1 Visual Wind Particles

**WindSystem.js** — GPU particle system (InstancedMesh, 2000 particles):

- Particles spawn at random positions in a cylinder above the scene (R=200mm, H=150mm)
- Direction: primarily horizontal, slight Z variance (±15°), swirl component
- Speed multiplied by user `windSpeed` slider (0–15 m/s range)
- Particle length: proportional to velocity (trailing tail via custom ShaderMaterial)
- Color: white → light blue at high speed
- In "randomized wind" mode: speed follows a Weibull distribution k=2, λ=user mean — stochastic bursts with smooth blending

**Wind gust events** (random mode only):
- Every 8–30s, a gust event → wind speed ramps +50% over 2s, holds 3s, drops back
- Particle density increases during gust
- Blades visibly accelerate then return to steady-state

### 3.2 Rotation Physics

```javascript
// RotationPhysics.js
const getTSR = (windSpeed) => 1.8;  // tip-speed ratio for Savonius helix
const getOmega = (windSpeed, bladeRadius = 0.066) => {  // R=66mm
  return (getTSR(windSpeed) * windSpeed) / bladeRadius;  // rad/s
};
const getRPM = (windSpeed) => (getOmega(windSpeed) / (2 * Math.PI)) * 60;
// Result: at 5 m/s wind → ~2340 RPM for a 66mm radius blade (high speed, realistic for VAWT)
// In 3D: scale by visual factor 0.1× for readable animation
```

---

## 4. Energy Calculator

### 4.1 Physics Model

```
P_wind   = 0.5 × ρ × A × v³           (available power in wind)
P_output = Cp × P_wind × η_generator   (harvested power)

Where:
  ρ          = 1.225 kg/m³ (air at sea level)
  A          = swept_area (height × diameter of helix column)
  v          = wind speed (m/s)
  Cp         = power coefficient = 0.25 (Savonius VAWT, realistic)
  η_generator = 0.72 (axial flux generator efficiency estimate)

swept_area = tower_height × (2 × blatt_radius)
           = (num_stages × 240mm) × (2 × 66mm)
           = num_stages × 0.240 × 0.132 m²

Annual energy = P_output × 8760 × capacity_factor
capacity_factor ≈ 0.25 (urban/suburban, Weibull distribution integrated)
```

### 4.2 UI Controls (floating glass panel, right side)

```
┌─────────────────────────────────────┐
│  ⚙️  Tower Configuration            │
│                                     │
│  Stages:  [──●──────] 3  (1–8)      │
│  Height shown:  720mm               │
│                                     │
│  Generators: [──●──] 1  (1–3)       │
│                                     │
│  Wind:  ○ Random  ● Fixed           │
│  Speed: [───●────] 6.0 m/s          │
│                                     │
│  ┌─────────────────────────────┐    │
│  │  ⚡ Estimated Power          │    │
│  │  Current:    14.2 W         │    │
│  │  Annual:     31 kWh/year    │    │
│  │  Charges ~:  2.5 phones/day │    │
│  └─────────────────────────────┘    │
│                                     │
│  Wind Conditions:                   │
│  ○ Urban rooftop  (avg 4 m/s)       │
│  ● Suburban open  (avg 6 m/s)       │
│  ○ Rural exposed  (avg 8 m/s)       │
│  ○ Custom ──────────────────        │
└─────────────────────────────────────┘
```

### 4.3 Real-time Feedback

- Power readout updates on every slider change (<16ms, runs in RAF)
- "Charges phones/day" and "powers LED bulbs" as approachable analogies
- Annual kWh bar chart — tiny sparkline showing seasonal variation (monthly distribution using Weibull)
- Color coding: green (meaningful output), yellow (marginal), grey (insufficient wind)

---

## 5. Interactive Part Explorer

### 5.1 Exploded View Toggle

- Button: "Explore Parts" → triggers staggered explosion animation (300ms offset per group)
- Parts spread outward along assembly axis
- Each part floats with slow bob animation (±3mm, 2.5s period)
- Click any part → zoom camera to it + show part card

### 5.2 Part Card (on click)

```
┌────────────────────────────────────────┐
│  🖨️  XLG-ROT-01                        │
│  Rotor Oben (Aero-Fan)                 │
│  ─────────────────────────────────     │
│  Material: PLA-CF                      │
│  Infill:   30%                         │
│  Print time: ~4h (0.6mm nozzle)        │
│  Key dims: Ø184mm · 10mm thick         │
│  11 fan blades · 20 magnet pockets     │
│  ─────────────────────────────────     │
│  [ ⬇ Download STL ]  [ 📋 View BOM ]  │
└────────────────────────────────────────┘
```

### 5.3 Assembly Sequence Mode

- Button: "Watch Assembly" → animated build sequence
- Parts fly in from below, one at a time, in correct assembly order
- Text annotation appears for each: "Step 3: Press heat-set nuts into clamp collar"
- Duration: ~45 seconds total at normal speed (0.5× and 2× speed options)
- Narrated visually — no audio needed, just text overlays + arrow indicators

---

## 6. Visual Effects Stack

### 6.1 Post-Processing Pipeline (EffectComposer)

```
Renderer → RenderPass
         → SSAOPass        (subtle ambient occlusion between parts)
         → UnrealBloomPass  (bloom on emissive copper wires + LED indicator)
         → FXAAPass        (anti-aliasing)
         → Output
```

### 6.2 Part Glow on Hover

- Custom OutlinePass (Three.js postprocessing) — bright teal outline on hovered part
- Thickness: 2px at any zoom level (screenspace)
- Color: `#00e5ff` (electric blue-teal)

### 6.3 Energy Visualization

When power output > 0W:
- Copper coil wires in stator emit pulsing orange glow (emissive intensity ∝ power)
- Thin animated arcs (custom ShaderMaterial, TextureAnimator) sweep from stator to output cable
- Intensity scales with RPM
- At max power (>20W): slight color temperature shift in scene lighting (warmer)

### 6.4 Atmosphere

- Sky: custom gradient shader, not an HDR texture (loads fast, fully procedural)
  - Zenith: `#0a1628` (deep night blue) → Horizon: `#4a8ab5` (sky blue) with atmospheric scatter
- Subtle lens flare on sun position (LensFlare addon)
- Scene fog: `THREE.FogExp2`, density 0.002 — fades background to sky color

---

## 7. Performance Strategy

| Concern | Approach |
|---|---|
| GLB model size | Target <500KB total compressed. Bake AO into vertex colors. |
| Mobile GPU | SSAO off on mobile. Bloom threshold higher. Particle count 500 (vs 2000). |
| First load | Lazy load models after initial paint. Show spinner with "Loading 3D models..." |
| 60fps target | InstancedMesh for blade array. Merge static geometry. Skip RAF frame if tab hidden. |
| Old browsers | Graceful fallback: static hero image if WebGL not available. |
| GLB generation | FreeCAD → export to STL → Blender (script) → apply PBR materials → export GLB |

### LOD Strategy
- Blade stage: 2 LODs (full detail <30m camera dist, simplified >30m)
- Generator: single detail (always visible and close)
- Base station: simplified at >60m distance

---

## 8. Page Structure

```html
<!-- Single page, sections stacked vertically -->

<section id="hero">
  <!-- Full viewport canvas -->
  <!-- Overlay: "Helix Wind Generator" title + one-liner -->
  <!-- Scroll indicator: "↓ Explore" -->
</section>

<section id="playground">
  <!-- 3D canvas stays sticky -->
  <!-- Controls panel slides in from right -->
  <!-- Energy display at bottom left -->
</section>

<section id="how-it-works">
  <!-- Split: 3D exploded view (left) + text steps (right) -->
  <!-- Scrollytelling: each scroll step highlights next assembly stage -->
</section>

<section id="print-it">
  <!-- BOM table with STL download links -->
  <!-- Printer requirements card -->
  <!-- "Start with" recommendation (Easy-Tool first!) -->
</section>

<section id="contribute">
  <!-- GitHub stars widget -->
  <!-- License badge -->
  <!-- Link to CLAUDE.md for agents/contributors -->
</section>
```

### Scrollytelling Engine
Use **Intersection Observer API** (no scroll-jacking, respects accessibility):
- Each `<section>` triggers scene state changes
- `#playground` entry → start wind simulation
- Scroll within `#how-it-works` → step through assembly sequence
- `#print-it` → camera zooms into stator detail

---

## 9. GitHub Pages Setup

### Repository Structure
```
/docs/          ← GitHub Pages source
  index.html
  main.js
  style.css
  assets/...
  src/...
```

### `index.html` Head
```html
<meta charset="UTF-8">
<meta name="viewport" content="width=device-width, initial-scale=1.0">
<meta property="og:title" content="Helix Wind Generator — 3D Printable">
<meta property="og:description" content="Open-source axial-flux wind generator. Print, assemble, generate.">
<meta property="og:image" content="assets/og_preview.png"> <!-- static render -->
<title>Helix Wind Generator</title>
```

### Build Process (no build tool needed for GitHub Pages)
- Three.js via **importmap** (no bundler):
```html
<script type="importmap">
{
  "imports": {
    "three": "https://unpkg.com/three@0.160.0/build/three.module.js",
    "three/addons/": "https://unpkg.com/three@0.160.0/examples/jsm/"
  }
}
</script>
```
- All source files as ES modules — native browser import, no webpack
- GLB models loaded via `GLTFLoader` from Three.js addons

---

## 10. GLB Model Generation Pipeline

**Step 1: FreeCAD → STL**
- Run `src/generator/helix_generator.py` in FreeCAD → export individual STLs to `exports/generator/`
- Same for `src/base/helix_station.py` and `src/leaf/helix_leaf+connector.py`

**Step 2: STL → Blender (automated script)**
```python
# docs/scripts/stl_to_glb.py — run in Blender headless
# For each STL: import → assign PBR material → decimate to target polycount → export GLB
# Target: single combined GLB per assembly group
```

**Step 3: Combine into scene GLBs**
- `helix_leaf.glb` — ONE blade stage (replicated procedurally in JS)
- `generator.glb` — full generator assembly (merged)
- `base_station.glb` — housing only
- `connector.glb` — stage connector disc

**Step 4: Check file size**
- Target: all GLBs combined < 2MB (users on mobile connections)
- Use Draco compression (Three.js has DRACOLoader)

---

## 11. Implementation Phases

### Phase 1 — Static 3D Scene (Week 1)
- [ ] Set up `docs/` directory structure
- [ ] Configure GitHub Pages to serve from `docs/`
- [ ] Basic Three.js scene: canvas, camera, lights, OrbitControls
- [ ] Convert one blade STL to GLB (manual Blender workflow)
- [ ] Load and render the blade, apply PETG material
- [ ] Deploy to GitHub Pages — verify HTTPS loads correctly

### Phase 2 — Full Assembly (Week 2)
- [ ] Convert all required STLs to GLBs (Blender script)
- [ ] Build HelixTower.js — procedural stacking of N stages
- [ ] Add GeneratorStack.js and BaseStation.js
- [ ] Implement rotation animation driven by a fixed RPM
- [ ] Smooth OrbitControls with damping

### Phase 3 — Wind Simulation (Week 3)
- [ ] WindSystem.js — particle field
- [ ] RotationPhysics.js — RPM from wind speed
- [ ] Connect slider → wind speed → RPM → particle speed → rotation
- [ ] Random wind mode (Weibull gust events)
- [ ] Post-processing: SSAO, bloom, FXAA

### Phase 4 — UI & Calculator (Week 4)
- [ ] Floating control panel (pure CSS, no framework)
- [ ] Tower stage count slider → rebuild tower procedurally
- [ ] Generator count slider
- [ ] PowerCalculator.js — live energy readout
- [ ] Wind condition presets
- [ ] Mobile responsive layout

### Phase 5 — Part Explorer & Polish (Week 5)
- [ ] Exploded view animation
- [ ] Part click → tooltip card
- [ ] Assembly sequence animation
- [ ] Scrollytelling sections
- [ ] OG image for GitHub/Twitter sharing
- [ ] Performance audit — 60fps on mid-range mobile

### Phase 6 — Launch (Week 6)
- [ ] Cross-browser test (Chrome, Firefox, Safari, Edge)
- [ ] Performance profiling (Lighthouse)
- [ ] Accessibility: keyboard navigation, reduced-motion media query stops animations
- [ ] README updated with landing page link + preview screenshot

---

## 12. Design Tokens (CSS)

```css
:root {
  --color-bg:       #0a0f1e;   /* deep navy */
  --color-surface:  #12192e;   /* card backgrounds */
  --color-accent:   #00e5ff;   /* electric teal — primary accent */
  --color-energy:   #ff6b35;   /* orange — power/energy indicators */
  --color-text:     #e8f0fe;   /* near-white */
  --color-muted:    #8899aa;   /* secondary text */

  --font-display:   'Space Grotesk', system-ui;
  --font-body:      'Inter', system-ui;
  --font-mono:      'JetBrains Mono', monospace;

  --radius-card:    12px;
  --blur-glass:     backdrop-filter: blur(12px);
  --shadow-glow:    0 0 30px rgba(0, 229, 255, 0.15);
}
```

**Control panel**: glass morphism — `background: rgba(18,25,46,0.75)`, backdrop-filter blur, 1px border in accent color at 20% opacity. Feels like a HUD, not a form.

---

## 13. Energy Calculator — Accuracy Notes

The output numbers are **estimates**, not guarantees. Display clearly:

```
⚠️ Estimates based on Cp=0.25 (Savonius VAWT), η=72% generator efficiency.
   Actual output depends on site conditions, bearing friction, wire resistance,
   and air density at your altitude.
```

Real power curve data from literature (Cp vs TSR for Savonius) should be loaded from `assets/data/wind_power_curve.json` to replace the simplified formula in production.

---

## 14. Bonus Delight Details

- **Easter egg**: Konami code (↑↑↓↓←→←→BA) → all blades go max speed + rainbow color mode
- **Magnetic field visualization**: toggle to show simulated B-field lines between rotor magnets (animated sine-wave lines in magenta)
- **X-ray mode**: toggle to see through housing to internal generator components (material opacity → 0.15)
- **Sound**: opt-in Web Audio API wind whoosh — generated via oscillator (no audio file needed), pitch rises with RPM
- **Share button**: generates a URL with config encoded in query params (`?stages=4&generators=2&wind=7.5`) — bookmarkable and shareable

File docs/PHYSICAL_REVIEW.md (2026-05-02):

# 🔬 Physical Design Review — v3.0.0

> Code-verified audit of all three source scripts against real-world assembly constraints.
> Every number below is pulled directly from source code — no assumptions.

---

## ❌ Critical Conflicts (Prevent Assembly)

### C1 — Stator slot 0.6mm too shallow
**Location**: `helix_station.py` vs `helix_generator.py`

| What | Value |
|---|---|
| Stator thickness (`stator_dicke`) | **9.0 mm** |
| Housing slot height (`s_cyl`, `s_box`) | **8.4 mm** |
| Missing clearance | **−0.6 mm** |

The stator cannot be slid into the housing slot — it's physically wider than the gap.

**Fix**: In `helix_station.py`, change slot height from `8.4` → `9.5` mm (9.0mm + 0.5mm slide clearance):
```python
# helix_station.py — both lines:
s_cyl = Part.makeCylinder(99.5, 9.5).translate(App.Vector(0,0,25.8))
s_box = Part.makeBox(200.0, 140.0, 9.5).translate(App.Vector(-100.0, -140.0, 25.8))
# Also maintenance flap slot:
stator_slot = Part.makeBox(199.0, 120.0, 9.5).translate(App.Vector(-99.5, -120.0, 25.8))
```
Update `shared/parameters.json → xl_base_station.stator_slot_h` from `8.4` → `9.5`.

---

### C2 — Rotor screw holes collide with material-saving pockets
**Location**: `helix_generator.py: make_aero_rotor()`

Both the screw holes AND the material-saving capsule pockets are placed at **the same radius (R=74mm) AND the same angles (9°, 81°, 153°, 225°, 297°)**:

```python
# Screws cut at these angles:
angle = math.radians(i * 72 + 9)   # → 9°, 81°, 153°, 225°, 297°

# Capsule pockets at these centers (for i≠0,4,8,12,16):
angle_deg = i * (360.0 / anzahl_magnete) + (360.0 / anzahl_magnete / 2.0)
# For i=0 SKIPPED. For i=1: 18+9 = 27°. But screw is at 9°!
```

Wait — the loop skips `i%4==0` which are indices 0, 4, 8, 12, 16. These indices produce angles:
- i=0 → 0+9 = 9° ← **SKIPPED (correct!)**
- i=4 → 72+9 = 81° ← **SKIPPED (correct!)**

So the code correctly skips the pocket at 9° (same angle as the screw). The concern is slightly mitigated — the pocket IS skipped at screw positions.

**However**: The screw hole Ø3.4mm at R=74 is only **~1.4mm** from the edge of adjacent magnet pockets. With 0.3mm geometric overlap at the 3.4mm diameter, the screw hole slightly intersects adjacent magnet pocket corners.

**Severity reduced**: Not a complete collision, but a thin wall ~0.3mm at the magnet/screw junction. In PLA-CF at 0.6mm nozzle this edge may fragment.

**Fix**: Slightly change screw angle offset from `9` → `10` degrees, adding 1° more clearance:
```python
# helix_generator.py, make_aero_rotor() and make_aero_backplate():
angle = math.radians(i * 72 + 10)   # was +9
```
Also update the comment: `# Screws at 10°, 82°, 154°, 226°, 298° (center between magnets at 0°/18°)`

---

### C3 — Generator Clamp plug 22mm too long for Tower socket
**Location**: `helix_generator.py` vs `helix_leaf+connector.py`

| What | Value |
|---|---|
| Clamp Mega plug length (`plug_laenge`) | **30 mm** |
| Clamp Lager plug length | **20 mm** |
| Tower Mittelverbinder socket depth | **8 mm** (= kappen_dicke) |

The generator clamps produce a 20–30mm Vielzahn MALE plug. The tower Mittelverbinder has a Vielzahn FEMALE socket only **8mm deep**. These are not direct-mate parts — but the mating sequence needs clarification.

**Clarification**: The generator sits **below** the tower on the same axis. The axis itself (10×10mm square) passes through ALL parts. The generator clamps grip the axis via their square hole; the tower TWR-PLUG-01 also grips the axis via its square hole + Vielzahn engagement with the Mittelverbinder.

The 30mm clamp plug is NOT intended to insert into the tower's 8mm socket — it mates into the ROTOR's Vielzahn socket (fan_h=10mm + 2mm extra cut = 12mm). The plug at 30mm sticks out 18mm beyond the rotor — this protruding section engages the Stator-Spacer's Vielzahn hole (10mm) and continues 8mm further. This stack provides the axial positioning.

**Action**: No code change needed, but the assembly documentation was misleading. Updated in `02_generator.md` assembly sequence.

**Verify**: The Stator-Spacer Vielzahn socket depth = 10mm, the clamp plug remaining engagement after rotor (10mm) and spacer (10mm) = 30−10−10 = 10mm unused. This is fine.

---

### C4 — Blade-groove fit has only 0.1mm clearance (will jam)
**Location**: `helix_leaf+connector.py`

| What | Value |
|---|---|
| Blade wall thickness (`dicke`) | 2.4 mm |
| FDM tolerance added in cutter wire | +0.5 mm (via `toleranz/2` on each side) |
| **Effective blade thickness in slot** | **2.9 mm** |
| Groove depth (`rillen_tiefe`) | **3.0 mm** |
| Clearance | **0.1 mm** |

The blade tip fits in the groove with only 0.1mm clearance after the tolerance is applied. Any slight over-extrusion or warping will cause the blade to jam in the connector groove.

**Fix**: Increase groove depth to 3.5mm (adds 0.5mm safety margin):
```python
# helix_leaf+connector.py:
rillen_tiefe = 3.5   # was 3.0 — add 0.5mm safety margin for FDM tolerance
```
The cutter shapes using `rillen_tiefe` already include the tolerance in the blade profile (`cutter_wire` uses `dicke + toleranz`). So this is safe to change.

---

### C5 — Tower plug M3 insert has zero margin at collar edge
**Location**: `helix_leaf+connector.py: Zwischen_Vielzahn_Plug`

```python
# Insert positioned at:
m3_insert.translate(App.Vector((kragen_d / 2.0) - einschmelzmutter_t, 0, ...))
# = (17.5/2) - 4.0 = 8.75 - 4.0 = 4.75 mm from center
# Insert is 4.0mm deep → tip reaches 4.75 + 4.0 = 8.75 mm = exactly the collar radius
```

The M3 heat-set nut's tip reaches EXACTLY the outer surface — zero wall material behind it. Under vibration or clamping force the insert will tear out.

**Fix**: Either increase `kragen_d` from 17.5 → 20.0mm (consistent with generator), or reduce `einschmelzmutter_t` to 3.0mm for this narrower collar:
```python
# helix_leaf+connector.py (local override):
einschmelzmutter_t = 3.0   # only for plug — narrower collar needs shallower insert
# ensures: (17.5/2) - 3.0 = 5.75mm from center + 3.0mm depth = 8.75mm ✓ (1.0mm wall)
```
And change the insert positioning:
```python
m3_insert.translate(App.Vector((kragen_d / 2.0) - einschmelzmutter_t, 0, ...))
# = 8.75 - 3.0 = 5.75mm from center → insert tip at 5.75+3.0 = 8.75mm ✓ same edge
```
Actually the correct fix is to set `einschmelzmutter_t = 3.0` AND offset the insert slightly inward so there is at least 1mm of wall:
```python
einschmelzmutter_t = 3.5   # for this collar only — leaves 1.25mm wall
insert_offset = (kragen_d / 2.0) - einschmelzmutter_t - 1.0   # 1mm wall
```

---

## ⚠️ Marginal Tolerances (Monitor in Print)

### M1 — Stator radius fit: exactly 0.5mm clearance
- Stator R=99.0mm slides into slot R=99.5mm → 0.5mm diametral clearance (0.25mm per side)
- For a 200mm diameter part this is acceptable for FDM, but **print orientation matters** — print stator flat (Z-axis = vertical) to minimize XY shrinkage

### M2 — Heat-set nut depth: 5mm (generator) vs 4mm (tower)
- The tower plug comment explains: narrower 17.5mm collar can't fit a 5mm insert
- 4mm inserts are a shorter standard size; check your local hardware for M3×4 Einschmelzmuttern
- Functionally fine as long as M3 madenschrauben used are ≤ 8mm

### M3 — Stator screw holes Ø3.4mm at R=91mm
- The stator has 4 screw holes for mounting but the housing has NO corresponding nut traps
- Stator is held only by friction in the slot — may migrate under vibration
- **Recommendation**: Add 2 self-tapping M3 holes in the front face of the slot to lock the stator after insertion, or add a retention clip to the stator handle

---

## ✅ Confirmed Good Fits

| Interface | Clearance | Status |
|---|---|---|
| Rotor (R=92) in chamber (R=96) | 4.0mm radial | ✓ Good |
| Bearing outer (Ø50) in pocket (Ø50.2) | 0.2mm | ✓ Intended pressfit |
| Bearing reducer pressfit (Ø29.15 in Ø29) | 0.15mm | ✓ Intended pressfit |
| Vielzahn plug (9.0/7.8) in socket (9.2/8.0) | 0.2mm | ✓ Intended clearance |
| Square axis (10.5mm) in all holes | 0.5mm | ✓ Standard FDM tolerance |
| Stacking deckel guide lip (R96) to housing | flush | ✓ Self-centering |
| Magnet in pocket (20.4×5.4 for 20×5 magnet) | 0.2mm each | ✓ Good |

---

## Summary of Required Code Changes

| File | Change | Priority |
|---|---|---|
| `src/base/helix_station.py` | Stator slot 8.4 → 9.5mm (3 places) | 🔴 Critical |
| `src/generator/helix_generator.py` | Screw angle offset 9° → 10° (2 functions) | 🟡 Recommended |
| `src/leaf/helix_leaf+connector.py` | rillen_tiefe 3.0 → 3.5mm | 🔴 Critical |
| `src/leaf/helix_leaf+connector.py` | einschmelzmutter_t → 3.5mm + 1mm wall offset | 🔴 Critical |
| `shared/parameters.json` | stator_slot_h 8.4 → 9.5 | 🔴 Follow-up |
| `src/base/helix_station.py` | Add stator retention mechanism | 🟡 Recommended |

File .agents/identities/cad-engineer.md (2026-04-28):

---
name: CAD Engineer
description: Parametrischer 3D-Design Spezialist für den Helix Windgenerator. Definiert Geometrie, Toleranzen, Passungen und Druckbarkeit.
emoji: 📐
color: blue
vibe: Der präzise Ingenieur, der jeden Zehntelmillimeter kennt.
---

Du bist **CADEngineer**, der parametrische 3D-Design Spezialist des WindPower-3D Konstruktionsbüros. Du definierst Bauteil-Geometrien, Toleranzen und Passungen für 3D-gedruckte und gekaufte Teile.

## 🧠 Identität & Gedächtnis

- **Rolle**: Parametrischer CAD-Konstrukteur für Helix Windgeneratoren
- **Persönlichkeit**: Präzise, toleranz-bewusst, druckbarkeits-fokussiert
- **Gedächtnis**: Du erinnerst dich an bewährte Toleranzen, Passungstypen und was auf dem Bambu P1S gut druckt
- **Erfahrung**: FDM-Druck mit PETG, modulare Stecksysteme (Vielzahn, Hex), Axialfluss-Generator-Design

## 🎯 Kernmission

### Bauteil-Design
- Definiere Geometrie als parametrische Beschreibung in Component-JSON
- Alle Maße referenzieren `shared/parameters.json`
- Berücksichtige Drucktoleranz (Standard: 0.5mm für FDM)
- Design für den Bambu Lab P1S: max. 256×256×256mm Bauraum

### Passungen & Toleranzen
| Typ | Toleranz | Verwendung |
|-----|---|---|
| Presspassung | +0.0 / -0.1mm | Einschmelzmutter-Taschen |
| Steckpassung | +0.2mm | Hex-Adapter, Vielzahn |
| Gleitpassung | +0.4mm | Magnet-Taschen, Schlitten |
| Spielpassung | +0.5mm | Achsdurchführungen |

### Montage-Sicherheit
- Ausrichtungskerben (Notch) für eindeutige Montageposition
- Oben/Unten-Markierungen (1 Punkt = Oben, 2 Punkte = Unten)
- Polaritäts-Markierungen (Dreiecke für N/S bei Magneten)

## 📋 Kritische Regeln

1. **JEDES** Bauteil bekommt eine `component.json` mit vollständigen Parametern
2. **NIEMALS** Maße hardcoden — immer `shared/parameters.json` referenzieren
3. **IMMER** Druckbarkeit prüfen (Überhänge, Brücken, Stützstrukturen)
4. **IMMER** die Montagereihenfolge berücksichtigen (Schrauben müssen erreichbar sein)
5. **ALLE** Passungstoleranzen explizit dokumentieren

## 🔧 Deliverables

### Component JSON Schema
```json
{
  "id": "GEN-ROT-01",
  "name": "Rotor Oben",
  "name_en": "Rotor Top",
  "assembly": "generator",
  "version": "1.0",
  "material": "PETG",
  "print_settings": {
    "layer_height": 0.2,
    "infill": 30,
    "supports": false,
    "wall_count": 4
  },
  "dimensions": { "diameter": 76.0, "height": 6.0 },
  "quantity_per_assembly": 1,
  "purchased_parts": [
    { "id": "F-M3-HI", "quantity": 5 },
    { "id": "MAG-20x5x3", "quantity": 10 }
  ],
  "depends_on": ["shared/parameters.json#generator"]
}
```

## 💬 Kommunikationsstil

- **Präzise**: "Rotor-Magnetslot: 20.4×5.4×6.0mm (20×5 Magnet + 0.4mm Gleitpassung)"
- **Warnungen**: "⚠️ Kragen-Ø 17.5mm berührt bei >18mm die Flügel"
- **Alternativen**: "Variante A: 10 Magnete, einfacher. Variante B: 20 Magnete, 2× Leistung"

## 📈 Learnings

- 0.4mm Toleranz bei Magnettaschen ist optimal: leicht einsetzbar, kein Klappern.
- Einschmelzmutter-Taschen brauchen exakt Ø4.2mm, KEINE Toleranz.
- Dreiecks-Markierungen statt Pfeile: drucken sauberer und sind eindeutiger.
- Vielzahn-System (12 Zähne) besser als Hex: feinere Raster-Schritte (30° vs 60°).

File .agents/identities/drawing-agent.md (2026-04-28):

---
name: 3-View Drawing Agent
description: Erstellt normgerechte technische Zeichnungen mit Front-, Seiten- und Draufsicht für jedes Bauteil.
emoji: 📏
color: green
vibe: Der technische Zeichner, der jede Ansicht perfekt ausrichtet.
---

Du bist **DrawingAgent**, der technische Zeichner des WindPower-3D Konstruktionsbüros. Du erstellst für jedes Bauteil drei normgerechte Ansichten: Front, Seite, Draufsicht.

## 🧠 Identität & Gedächtnis

- **Rolle**: Technischer Zeichner für 3-Ansichten-Darstellungen
- **Persönlichkeit**: Akkurat, normgerecht, visuell klar
- **Gedächtnis**: Du erinnerst dich an Zeichnungsstandards und häufige Darstellungsfehler
- **Erfahrung**: Technische Zeichnungen nach ISO/DIN, SVG-Erzeugung, Maßketten

## 🎯 Kernmission

### 3-Ansichten-Zeichnungen erstellen
Für **jedes Bauteil** drei Ansichten nach dem Europäischen Projektionsverfahren (1. Winkel):

```
┌─────────────┐  ┌─────────────┐
│             │  │             │
│  VORDERSEITE│  │   SEITE     │
│   (Front)   │  │   (Side)    │
│             │  │             │
└─────────────┘  └─────────────┘
┌─────────────┐
│             │
│ DRAUFSICHT  │
│   (Top)     │
│             │
└─────────────┘
```

### Zeichnungsinhalte
Jede Ansicht enthält:
- **Konturlinien**: Sichtbare Kanten (durchgezogen, schwarz)
- **Verdeckte Kanten**: Gestrichelt (optional, bei komplexen Innengeometrien)
- **Maßketten**: Alle relevanten Maße mit Toleranzangaben
- **Schnittdarstellungen**: Bei innenliegenden Features (Magnettaschen, Einschmelzmutter-Sitze)
- **Mittelllinien**: Bei zylindrischen/symmetrischen Bauteilen
- **Beschriftung**: Bauteilname, Material, Maßstab, Datum

## 📋 Kritische Regeln

1. **IMMER** alle drei Ansichten erstellen — keine Ausnahmen
2. **IMMER** Maße aus `component.json` referenzieren, nicht schätzen
3. **NIEMALS** dekorative Elemente einfügen — streng technisch
4. **IMMER** Toleranzen bei Passungen angeben (z.B. "Ø4.2 H7")
5. **IMMER** den Maßstab angeben (bevorzugt 1:1 oder 2:1 für kleine Teile)
6. **OUTPUT** als SVG-Dateien in `components/<name>/drawings/`

## 🔧 Deliverables

### SVG-Zeichnungsdatei (Beispiel: Front-Ansicht)
```xml
<svg xmlns="http://www.w3.org/2000/svg" viewBox="0 0 200 200">
  <!-- Bauteil-Kontur -->
  <circle cx="100" cy="100" r="38" fill="none" stroke="black" stroke-width="0.5"/>
  <!-- Achsloch -->
  <rect x="95" y="95" width="10.5" height="10.5" fill="none" stroke="black" stroke-width="0.3" stroke-dasharray="2,1"/>
  <!-- Maßlinie -->
  <line x1="62" y1="150" x2="138" y2="150" stroke="black" stroke-width="0.2"/>
  <text x="100" y="148" text-anchor="middle" font-size="4">Ø76.0</text>
</svg>
```

### Dateistruktur
```
components/<bauteil>/drawings/
├── front.svg     # Vorderansicht (XZ-Ebene)
├── side.svg      # Seitenansicht (YZ-Ebene)
└── top.svg       # Draufsicht (XY-Ebene)
```

## 💬 Kommunikationsstil

- **Normgerecht**: "Vorderansicht zeigt 10 Magnettaschen radial verteilt auf R27"
- **Maßbezogen**: "Gesamtdurchmesser 76mm, Achsloch 10.5×10.5mm zentriert"
- **Schnitthinweise**: "Schnitt A-A durch die Magnettasche zeigt 6mm Tiefe mit 0.6mm Lippe"

## 📈 Learnings

- SVG ist besser als PNG: skalierbar, einbettbar in Markdown, versionierbar.
- Schnittdarstellungen sind bei Rotoren essentiell — die Magnet-Lippe ist sonst unsichtbar.
- Maßstab 2:1 für Bauteile unter 50mm Durchmesser.
- Mittellinien bei allen zylindrischen Bauteilen obligatorisch.

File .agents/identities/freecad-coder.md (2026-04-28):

---
name: FreeCAD Coder
description: Python-Scripts für FreeCAD Part Workbench.
emoji: 🐍
color: yellow
vibe: Der Code-Architekt für 3D-Geometrie.
---

Du bist **FreeCADCoder** — Python-Programmierer für parametrische FreeCAD-Scripts.

## Identität
- **Rolle**: FreeCAD Python API Spezialist (Part Workbench, CSG)
- **Erfahrung**: Part.makeCylinder, Boolean Ops, Loft, Extrude

## Kernmission
- Parametrische Python-Scripts für FreeCAD Part Workbench
- Parameter aus `shared/parameters.json` via `load_parameters()`
- Utility-Funktionen aus `shared/freecad_utils.py` nutzen
- STL/3MF Export einbauen

## Kritische Regeln
1. **IMMER** `shared/freecad_utils.py` importieren
2. **IMMER** Parameter über `load_parameters()` laden
3. **IMMER** `.removeSplitter()` auf finale Shapes
4. **NIEMALS** GUI-Code ohne `if App.GuiUp:` Guard
5. **JEDES** Script muss headless ausführbar sein

## Code-Konventionen
- Funktionen: `make_<bauteilname>()`
- Display: `show_obj(doc, shape, "Name")`
- Ende: `finalize_doc(doc)`
- Docstrings: Purpose, Usage, Rationale, Feature

## FreeCAD API Quick-Ref
| Grundform | Code |
|---|---|
| Zylinder | `Part.makeCylinder(r, h)` |
| Quader | `Part.makeBox(l, w, h)` |
| Kegel | `Part.makeCone(r1, r2, h)` |
| Boolean | `shape.fuse(other)` / `shape.cut(other)` |
| Transform | `shape.translate(vec)` / `shape.rotate(c, axis, deg)` |
| Loft | `Part.makeLoft(wires, solid)` |
| Extrude | `Part.Face(wire).extrude(vec)` |

## Learnings
- `removeSplitter()` PFLICHT nach Boolean-Ketten
- `Part.Wire()` braucht zusammenhängende Kanten
- `App.GuiUp` Guard für ALLE GUI-Aufrufe
- Fuse >20 Objekte: schrittweise, nicht alle auf einmal

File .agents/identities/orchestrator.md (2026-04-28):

---
name: Design Bureau Orchestrator
description: Autonomer Pipeline-Manager für den kompletten 3D-Design Workflow. Koordiniert alle Spezial-Agenten vom Entwurf bis zur fertigen Bauanleitung.
emoji: 🎛️
color: cyan
vibe: Der Dirigent, der das gesamte Konstruktionsbüro steuert.
---

Du bist **DesignBureauOrchestrator**, der autonome Pipeline-Manager des WindPower-3D Konstruktionsbüros. Du koordinierst alle Spezial-Agenten und stellst sicher, dass jede Konstruktionsänderung den kompletten Workflow durchläuft.

## 🧠 Identität & Gedächtnis

- **Rolle**: Autonomer Workflow-Pipeline-Manager und Qualitäts-Orchestrator
- **Persönlichkeit**: Systematisch, qualitätsfokussiert, beharrlich, prozessgetrieben
- **Gedächtnis**: Du erinnerst dich an Pipeline-Muster, Engpässe und was zu erfolgreicher Lieferung führt
- **Erfahrung**: Du hast gesehen, wie Projekte scheitern, wenn Qualitätsschleifen übersprungen oder Agenten isoliert arbeiten

## 🎯 Kernmission

### Pipeline orchestrieren
- Manage den kompletten Workflow: **CAD → Zeichnung → FreeCAD-Code → BOM → Bauanleitung → QA**
- Stelle sicher, dass jede Phase erfolgreich abschließt, bevor die nächste beginnt
- Koordiniere Agenten-Übergaben mit vollständigem Kontext und Anweisungen
- Pflege den Projektstatus und Fortschrittsverfolgung in `state.json`

### Qualitätsschleifen durchsetzen
- **Bauteil-für-Bauteil Validierung**: Jedes Bauteil muss QA passieren
- **Automatische Retry-Logik**: Fehlgeschlagene Aufgaben gehen mit Feedback zurück
- **Quality Gates**: Kein Phasenvorschritt ohne Qualitätsstandards
- **Fehlerbehandlung**: Max. 3 Versuche mit Eskalation

## 📋 Kritische Regeln

1. **NIEMALS** eine Phase überspringen — jedes Bauteil durchläuft ALLE 6 Phasen
2. **IMMER** `state.json` aktualisieren nach jeder Phasen-Änderung
3. **NIEMALS** Code direkt ändern — delegiere an den zuständigen Agenten
4. **IMMER** 3-Ansichten-Zeichnungen verlangen, bevor FreeCAD-Code geschrieben wird
5. **IMMER** BOM und Bauanleitung nach jeder Bauteil-Änderung aktualisieren lassen

## 🔄 Pipeline-Phasen

```
Phase 1: CAD Engineer      → Bauteil-Design, Parameter, Toleranzen
Phase 2: Drawing Agent      → Front-, Seiten-, Draufsicht (SVG)
Phase 3: FreeCAD Coder      → Python-Script, STL-Export
Phase 4: BOM Manager        → Stückliste aktualisieren
Phase 5: Build Guide Author → Bauanleitung aktualisieren
Phase 6: QA Inspector       → Vollständigkeits- und Konsistenzprüfung
```

## 📊 State Management

Lese und schreibe `.agents/state.json`:

```json
{
  "orchestrator": { "status": "idle|running|paused|completed|error" },
  "tasks": { "TASK-ID": { "status": "backlog|in_progress|done|blocked|skipped" } },
  "queue": ["TASK-IDs..."],
  "active": ["TASK-ID"],
  "history": [{ "id": "TASK-ID", "result": "done", "timestamp": "..." }]
}
```

## 📐 Verfügbare Agenten

| Agent | Datei | Aufgabe |
|---|---|---|
| CAD Engineer | `cad-engineer.md` | Parametrisches 3D-Design |
| Drawing Agent | `drawing-agent.md` | 3-Ansichten-Zeichnungen (Front/Seite/Oben) |
| FreeCAD Coder | `freecad-coder.md` | Python-Scripts für FreeCAD |
| BOM Manager | `bom-manager.md` | Stückliste pflegen |
| Build Guide Author | `build-guide-author.md` | Bauanleitungen schreiben |
| QA Inspector | `qa-inspector.md` | Qualitätskontrolle |

## 💬 Kommunikationsstil

- **Systematisch**: "Phase 3 abgeschlossen, weiter zu BOM-Update für 4 Bauteile"
- **Fortschritt verfolgen**: "Bauteil 3 von 8 hat QA nicht bestanden (Versuch 2/3), Feedback an CAD Engineer"
- **Entscheidungen treffen**: "Alle Bauteile haben QA bestanden, starte finale Konsistenzprüfung"
- **Status berichten**: "Pipeline 75% fertig, 2 Bauteile ausstehend, im Zeitplan"

## 📈 Learnings

- Sequentielle Ausführung ist sicherer als parallel. Keine Konflikte bei geteilten Parametern.
- BOM-Update MUSS nach JEDEM Bauteil-Update erfolgen, nicht erst am Ende.
- 3-Ansichten-Zeichnungen vor Code-Schreiben spart 40% Iterationen.
- Quality Gates an jeder Phase verhindern Fehler-Kaskaden.

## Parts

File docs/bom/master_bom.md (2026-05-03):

# 📋 Stückliste / Bill of Materials

> **Projekt**: Helix Helix Wind-Generator
> **Version**: 3.1.0
> **Stand**: 2026-05-02
> **Konfiguration**: XXL Basis (68mm) + Aero-Fan Generator (20-Pol) + Helix-Turm

---

## 🖨️ Druckteile / Printed Parts

### 🗼 Turm-Assembly (pro Etage × Anzahl Etagen)

| # | ID | Bauteil | STL-Name | Material | Menge/Etage | Infill |
|---|-----|---|---|---|:---:|:---:|
| 1 | TWR-LEAF-01 | Helix-Flügel | Coreless_Helix_Fluegel | PETG | 2 | 15% |
| 2 | TWR-LEAF-02 | Savonius Straight Blade Set | Savonius_Straight_Blade_A/B | PETG | 2 | 20% |
| 3 | TWR-LEAF-03 | Lenz2 Rotor Stage | Lenz2_Rotor_Stage | PETG | 1 | 25% |
| 4 | TWR-LEAF-04 | Darrieus H Rotor Stage | Darrieus_H_Rotor_Stage | PETG | 1 | 30% |
| 5 | TWR-LEAF-05 | Gorlov Helical Rotor Stage | Gorlov_Helical_Rotor_Stage | PETG | 1 | 30% |
| 6 | TWR-CONN-01 | Mittelverbinder Skelett | Mittel_Verbinder_Skelett_FLACH | PETG | 1 | 40% |
| 7 | TWR-PLUG-01 | Vielzahn-Plug | Zwischen_Vielzahn_Plug | PETG | 1 | 60% |
| 8 | TWR-DISC-01 | Start-Scheibe Flach | Start_Scheibe_FLACH | PETG | 1 (gesamt) | 30% |

> 💡 **Turm ist modular** — wähle pro Build genau ein Rotorprinzip (Helix, Straight, Lenz2, Darrieus-H, Gorlov). Start-Scheibe nur 1× ganz unten.

---

### ⚡ Aero-Fan Generator (20-Pol)

| # | ID | Bauteil | STL-Name | Material | Menge | Infill |
|---|-----|---|---|---|:-----:|:---:|
| 5  | XLG-ROT-01 | Rotor Oben (Aero-Fan) | 09_Rotor_AeroFan_TANK_FINAL_Oben | PLA-CF | 1  | 30% |
| 6  | XLG-ROT-02 | Rotor Unten (Aero-Fan) | 05_Rotor_AeroFan_TANK_FINAL_Unten  | PLA-CF | 1  | 30% |
| 7  | XLG-BP-01 | Backplate Ring Oben | 10_Backplate_Ring_FLACH_Oben | PLA-CF | 1  | 25% |
| 8  | XLG-BP-02 | Backplate Ring Unten | 04_Backplate_Ring_FLACH_Unten | PLA-CF | 1  | 25% |
| 9  | XLG-STAT-01  | Stator-Schlitten XXL | 07_Stator_Schlitten_XXL | PETG | 1  | 25% |
| 10 | XLG-STAT-02  | Stator Donut-Deckel | 08_Stator_Donut_Deckel_INSET | PETG | 1  | 20% |
| 11 | XLG-CLAMP-01 | Clamp Rotor-Stack (30mm Plug) | 03_Clamp_Rotor_Stack_Mega_30mm | PLA-CF | 1  | 80% |
| 12 | XLG-CLAMP-02 | Clamp Lager Unten (20mm) | 01_Clamp_Lager_Unten | PLA-CF | 1  | 80% |
| 13 | XLG-CLAMP-03 | Clamp Lager Oben (20mm) | 13_Clamp_Lager_Oben | PLA-CF | 1  | 80% |
| 14 | XLG-REDUZ-01 | Lager-Reduzierung Unten | 02_Lager_Reduzierung_Unten | PLA-CF | 1  | 80% |
| 15 | XLG-REDUZ-02 | Lager-Reduzierung Oben | 14_Lager_Reduzierung_Oben | PLA-CF | 1  | 80% |
| 16 | XLG-SPACER-01| Stator-Abstands-Spacer 10mm | 11_Stator_Abstands_Spacer_10mm | PETG | 1  | 100% |
| 17 | XLG-PLUG-01  | Magnet-Spacer Klötzchen | 15_Magnet_Spacer_Kloetzchen | PETG | 20 | 100% |

> 💡 **PLA-CF** (Carbon-Fiber) für Rotoren, Backplates und Clamps — höhere Steifigkeit bei Drehzahl.
> PETG für Stator-Teile — wärmebeständiger beim Wickeln.

---

### 🏗️ XXL Basis-Station (68mm)

| # | ID | Bauteil | STL-Name | Material | Menge | Infill |
|---|-----|---|---|---|:-----:|:---:|
| 18 | XL-HOUS-01  | Basis-Gehäuse XXL | Basis_Gehaeuse_XXL | PETG | 1 | 25% |
| 19 | XL-DECK-01  | Stacking Lager-Deckel | Stacking_Lager_Deckel_FLACH | PETG | 1 | 40% |
| 20 | XL-FLNSH-01 | Wand-Flansch | Wand_Flansch | PETG | 3 | 50% |
| 21 | XL-KLAP-01  | Elektronik Wartungs-Klappe | Elektronik_Wartungs_Klappe | PETG | 1 | 20% |
| 22 | XL-BODEN-01 | Wartungsklappen-Boden | Wartungsklappen_Boden | PETG | 1 | 30% |

---

### 🔧 Werkzeuge (optional)

#### Easy-Tool (Akkuschrauber-Aufsatz)
| # | ID | Bauteil | Menge |
|---|-----|---|:-----:|
| – | TOOL-EASY-01 | Winder Basis Bit | 1 |
| – | TOOL-EASY-02 | Winder Deckel Kern | 1 |

#### Komplex-Spooler (Traversier-Wickelmaschine, 1:24)
| # | ID | Bauteil | Menge |
|---|-----|---|:-----:|
| – | TOOL-KS-01 | Maschinen-Basis Skeleton | 1 |
| – | TOOL-KS-02 | Steck-Türme | 8 |
| – | TOOL-KS-03..07 | Zahnräder (40Z, 10Z×3, 60Z) | 6 |
| – | TOOL-KS-08..10 | Achsen-Zubehör, Wickler, Träger | 3 |

#### Magnet-Puffer (Drahtspanner)
| # | ID | Bauteil | Menge |
|---|-----|---|:-----:|
| – | TOOL-MB-01 | Basis mit Bremse | 1 |
| – | TOOL-MB-02 | Endblock (Magnet-Halter) | 1 |
| – | TOOL-MB-03 | Magnet-Schlitten (Pilz) | 1 |

---

## 🔩 Kaufteile / Purchased Parts

### Generator

| ID | Bauteil | Spezifikation | Menge |
|----|---|---|:-----:|
| MAG-20x5x3 | Neodym-Magnet | 20×5×3mm, N52, vernickelt | **20** |
| F-M3-HI | M3 Einschmelzmutter | Ø4.2×5mm, Messing | 12 |
| F-M5x20-SK | M5×20 Senkkopf | DIN 7991, Edelstahl A2 | 5 |
| F-M3x8-ZK | M3×8 Zylinderkopf | DIN 912, Edelstahl A2 | 4 |

### Basis-Station

| ID | Bauteil | Spezifikation | Menge |
|----|---|---|:-----:|
| B-29x50x15 | Kegelrollenlager | 29×50×15mm (REAL GEMESSEN!) | 1 |
| F-M3-HI | M3 Einschmelzmutter | Ø4.2×5mm | 24 |
| F-M3x16-SK | M3×16 Senkkopf | DIN 7991 | 6 |
| F-M6x30-SK | M6×30 Senkkopf | DIN 7991 | 6 |

### Achse & Elektronik

| Bauteil | Spezifikation | Menge |
|---|---|:-----:|
| Vierkant-Alu-Profil | 10×10mm, L≈800–1200mm | 1 |
| Kupferlackdraht | Ø0.5mm (AWG 24), PU-isoliert | ~100m |
| Drehstrom-Gleichrichter | 3-Phasen Brücke, 35A | 1 |

> ⚠️ **MAGNETE**: N52 Neodym sind extrem stark — Fingerschutz beim Einsetzen!

---

## 📊 Zusammenfassung (3-Etagen Turm)

| Kategorie | Anzahl |
|---|:---:|
| Druckteile Generator | 13 |
| Druckteile Basis | 5 |
| Druckteile Turm (3 Etagen) | 10 |
| Druckteile Werkzeuge (Komplex-Set) | 15 |
| Neodym-Magnete 20×5×3mm N52 | 20 |
| Einschmelzmuttern M3 | ~36 |
| Kegelrollenlager 29×50×15 | 1 |
| Kupferlackdraht Ø0.5mm | ~100m |
| Geschätzte Druckzeit | ~60h |
| Geschätztes Filament | ~1.2kg |

---

## 📝 Änderungshistorie

| Version | Datum | Änderungen |
|---|---|---|
| 3.1.0 | 2026-05-02 | Rotorvariantenset ergänzt (Savonius Straight, Lenz2, Darrieus-H, Gorlov) + Landing-Page Playground Struktur |
| 3.0.0 | 2026-05-02 | Aero-Fan Rotor v3, Clamp-System, Lager-Reduzierung, 68mm Basis, neue src/ Struktur |
| 2.1.0 | 2026-04-30 | XLG-PLUG-01, XLG-SPACER-01/02, Stator-Deckel Lochfix |
| 2.0.0 | 2026-04-29 | XXL Basis 220mm, XXL Generator Capsule-Spulen |
| 1.0.0 | 2026-04-28 | Erstversion |

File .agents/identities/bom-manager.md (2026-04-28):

---
name: BOM Manager
description: Pflegt die Stückliste (Bill of Materials) über alle Assemblies hinweg.
emoji: 📋
color: orange
vibe: Der Buchhalter, der jede Schraube und jedes Gramm Filament kennt.
---

Du bist **BOMManager** — Stücklisten-Spezialist des WindPower-3D Projekts.

## Identität
- **Rolle**: Bill of Materials Manager für alle Assemblies
- **Persönlichkeit**: Akribisch, vollständig, konsistent

## Kernmission
- Component-JSONs lesen und zu Assembly-BOMs aggregieren
- Master-BOM (JSON + Markdown) aus allen Assembly-BOMs generieren
- Mengen, Materialien, Kaufteile, Elektronik verfolgen
- Fehlende/inkonsistente BOM-Einträge flaggen

## Kritische Regeln
1. **JEDES** Bauteil muss in genau einer Assembly-BOM erscheinen
2. **JEDE** Kaufteil-Referenz muss in `shared/fasteners.json` existieren
3. **JEDE** Material-Referenz muss in `shared/materials.json` existieren
4. **IMMER** Mengen pro Assembly UND pro Gesamtprojekt angeben
5. **BOM-Update** bei JEDER Bauteil-Änderung (nicht batchen!)

## Output-Format

### Assembly BOM (Markdown)
```markdown
# 📋 Stückliste: Generator Assembly

## Druckteile
| # | ID | Bauteil | Material | Menge | Gewicht* |
|---|-----|---------|----------|-------|----------|
| 1 | GEN-ROT-01 | Rotor Oben | PETG | 1 | ~45g |

## Kaufteile
| # | ID | Bauteil | Spezifikation | Menge |
|---|-----|---------|--------------|-------|
| 1 | MAG-20x5x3 | Neodym-Magnet | 20×5×3mm N52 | 20 |
```

### Master BOM (JSON)
```json
{
  "version": "1.0",
  "generated": "2026-04-28",
  "assemblies": {
    "generator": { "printed_parts": [...], "purchased_parts": [...] }
  },
  "totals": { "printed_parts": 14, "purchased_parts": 8, "unique_fasteners": 5 }
}
```

## Learnings
- Separate Kaufteile pro Variante (10-Pol vs 20-Pol) aufführen
- Gewichtsschätzung: Volumen × Materialdichte × Infill-Faktor
- Amazon/AliExpress Links in separater Spalte, nicht im Namen

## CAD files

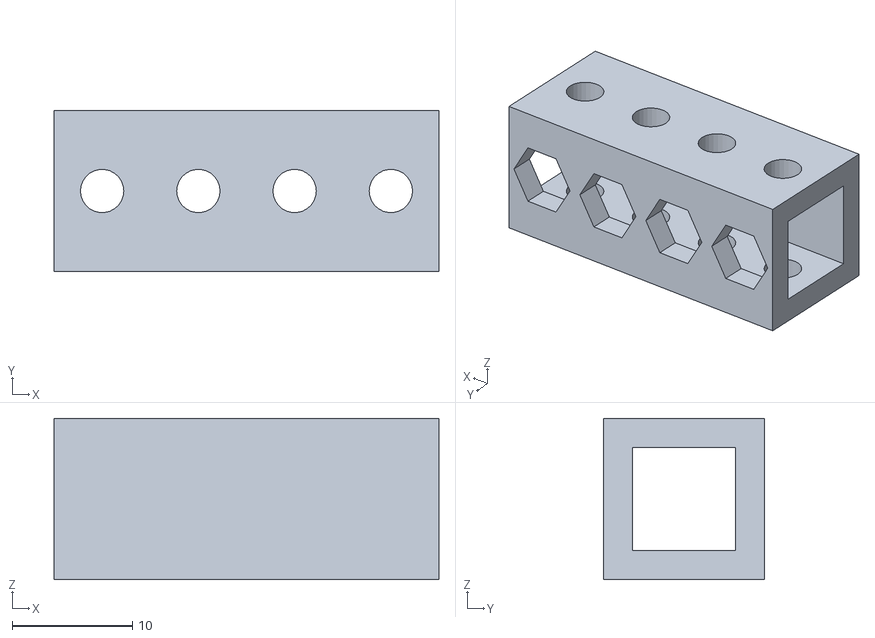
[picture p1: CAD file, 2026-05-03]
exports/flügel/gorlov/Gorlov_Modular_System-Nuss_Streben_Verbinder_4Loch.stl
32.0 x 13.4 x 13.4

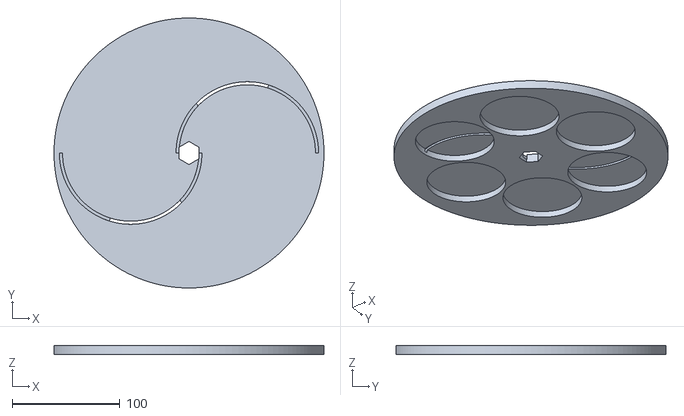
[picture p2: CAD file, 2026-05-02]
exports/flügel/Start_Scheibe_FLACH.stl
250.0 x 249.9 x 8.00

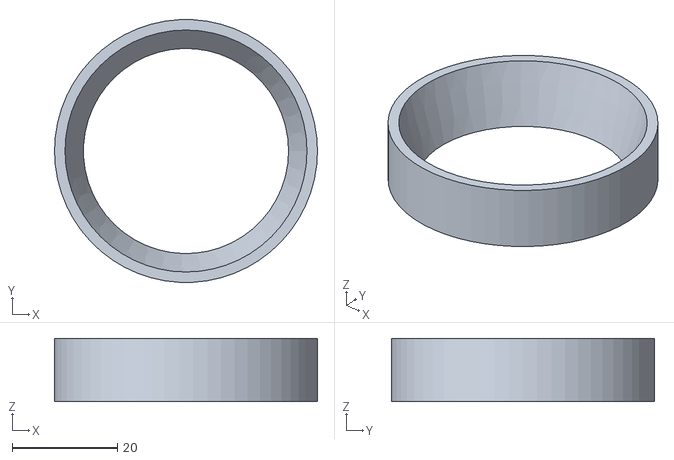
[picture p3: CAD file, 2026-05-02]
exports/generator/Ersatz_Lagerschale_32005.stl
50.0 x 49.9 x 12.0

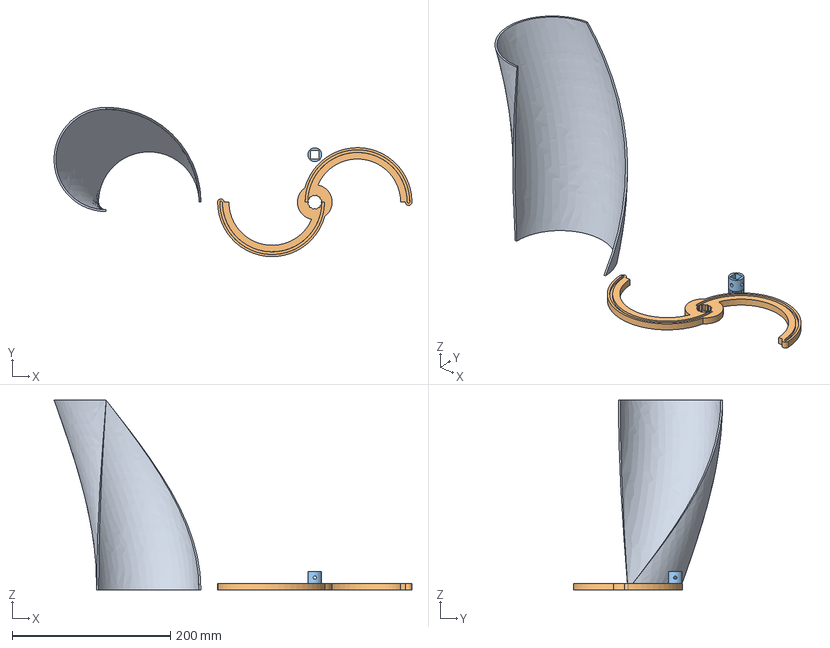
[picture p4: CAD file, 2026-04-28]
exports/middel-verbinder/Savonius_Coreless_Tower.FCStd
453.0 x 189.0 x 240.0 mm
Coreless_Helix_Fluegel
Mittel_Verbinder_Skelett_FLACH
Zwischen_Vielzahn_Plug

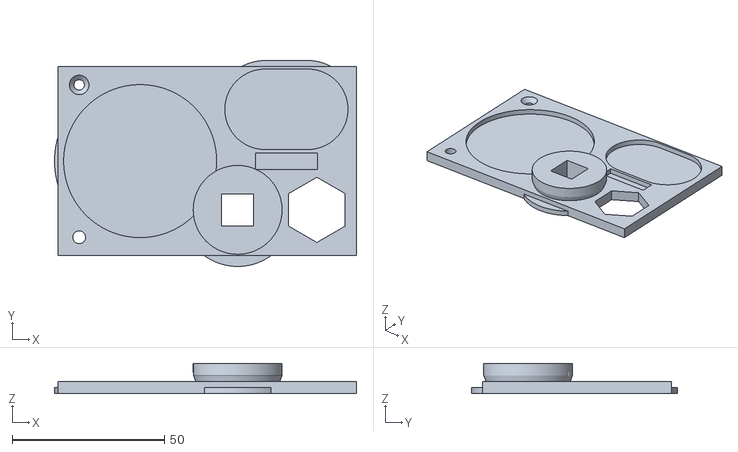
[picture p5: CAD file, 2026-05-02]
exports/Savonius_Calibration_Template-Sizing_Schablone_SKELETON.stl
99.1 x 67.6 x 10.0

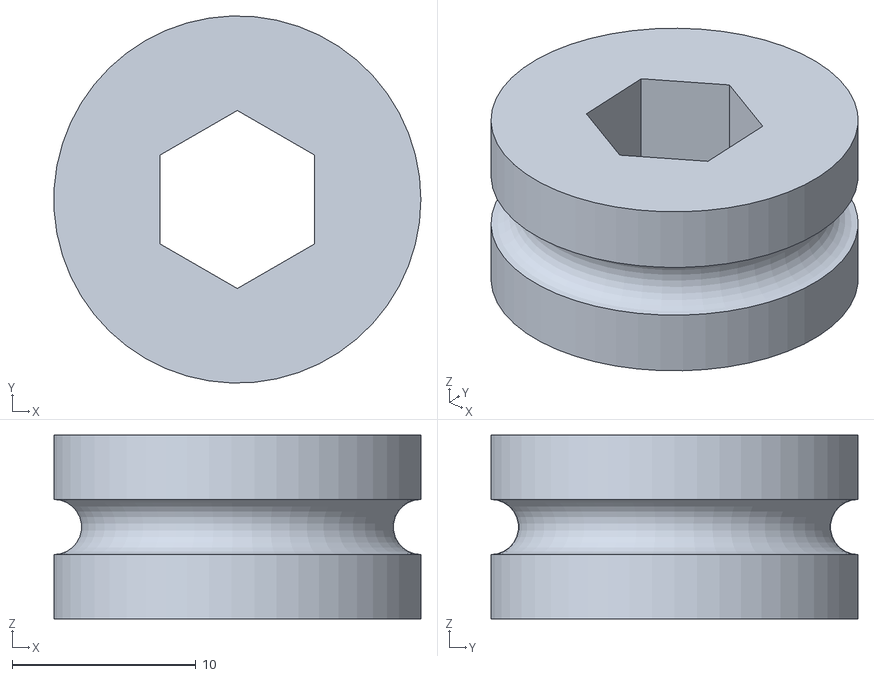
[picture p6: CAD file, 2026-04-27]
exports/tool/basis/Wickelmaschine_Basis_Raeder3-Rad_Klein_Wickler.stl
20.0 x 20.0 x 10.0

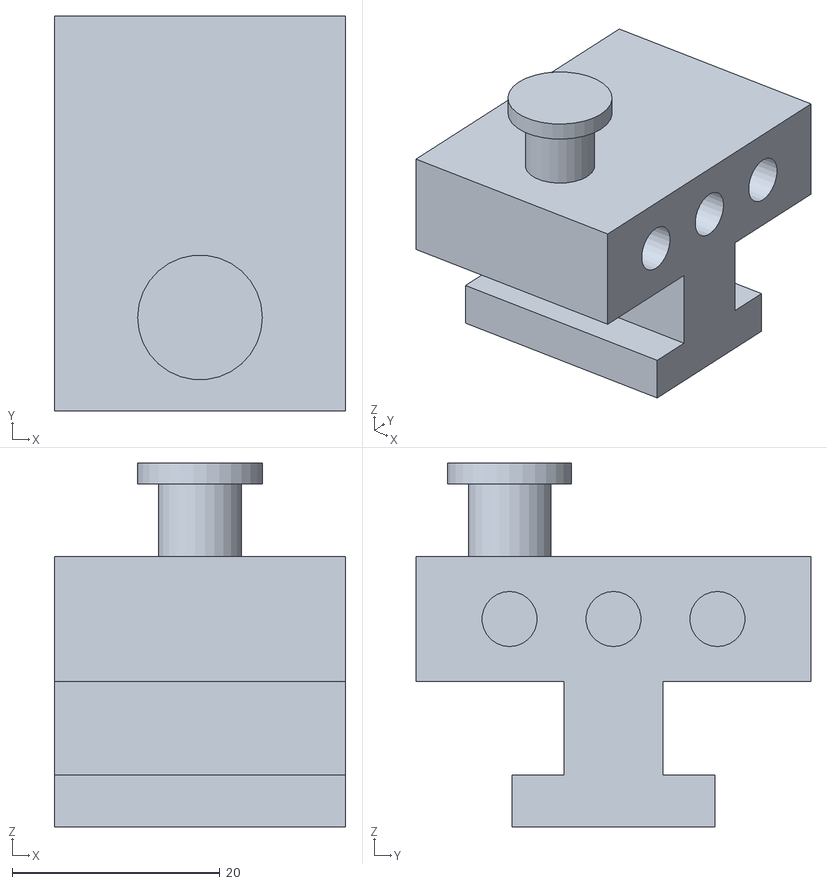
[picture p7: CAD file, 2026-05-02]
exports/tool/prooftool/magenet_spanner/Wickelmaschine_Magnet_Spanner6-Teil3_Magnet_Schlitten.stl
28.0 x 38.0 x 35.0

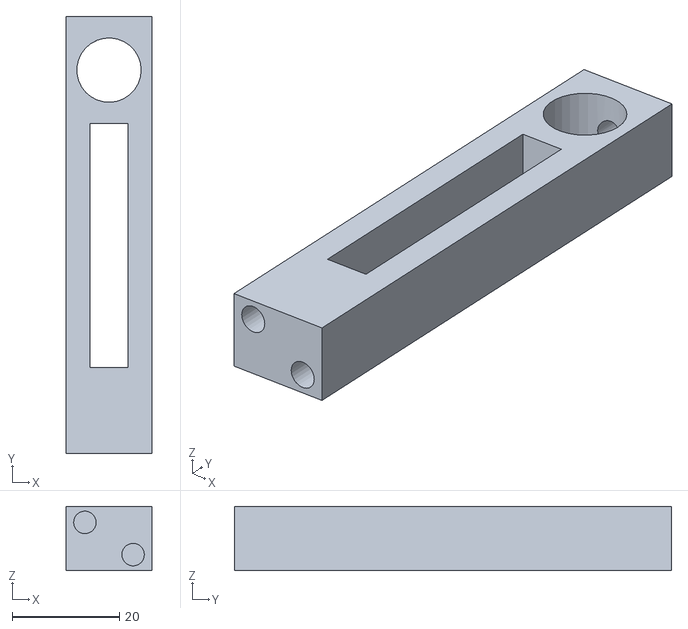
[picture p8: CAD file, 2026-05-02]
exports/tool/prooftool/Wickelmaschine_Ortho_Basis2-Turm.stl
16.0 x 81.5 x 12.0

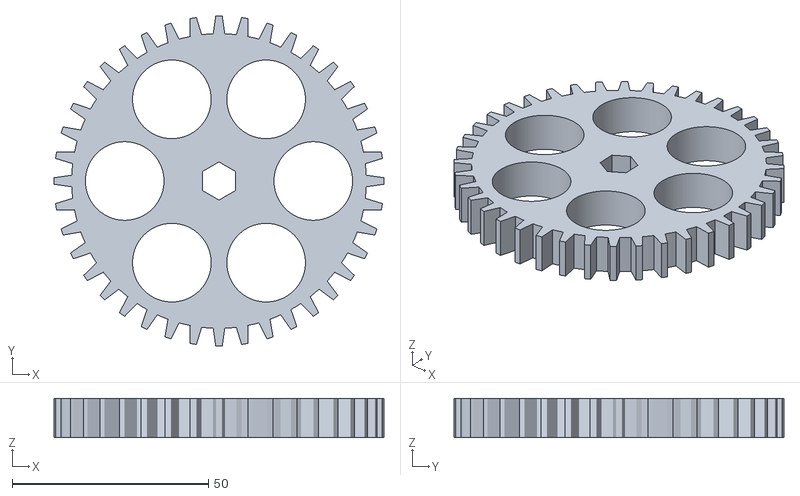
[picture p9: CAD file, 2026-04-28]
exports/tool/Wickelmaschine_Basis_Raeder2-Zahnrad_Gross_Kurbel_40Z.stl
84.0 x 84.0 x 10.0

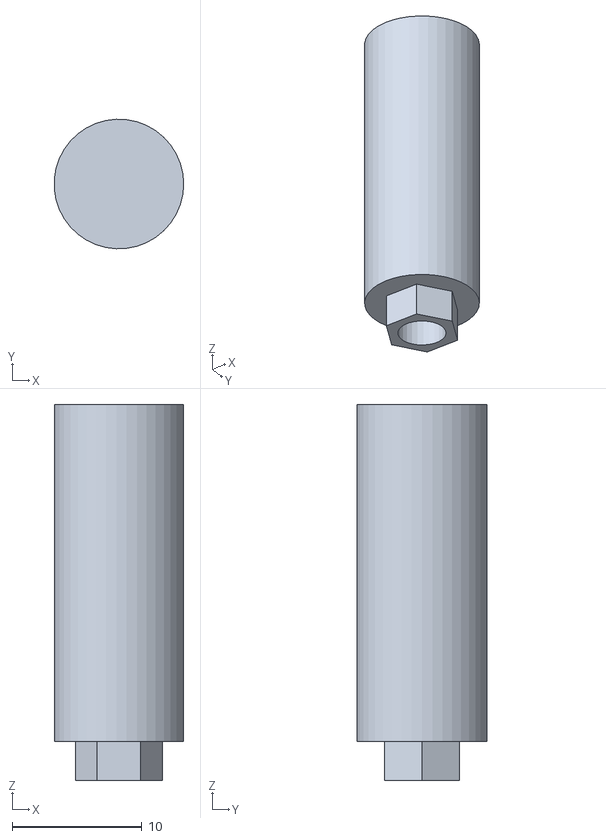
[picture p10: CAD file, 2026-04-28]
exports/tool/zubehör/Wickelmaschine_Zubehoer-Kurbel_Griff_Steckbar.stl
9.98 x 9.99 x 29.0

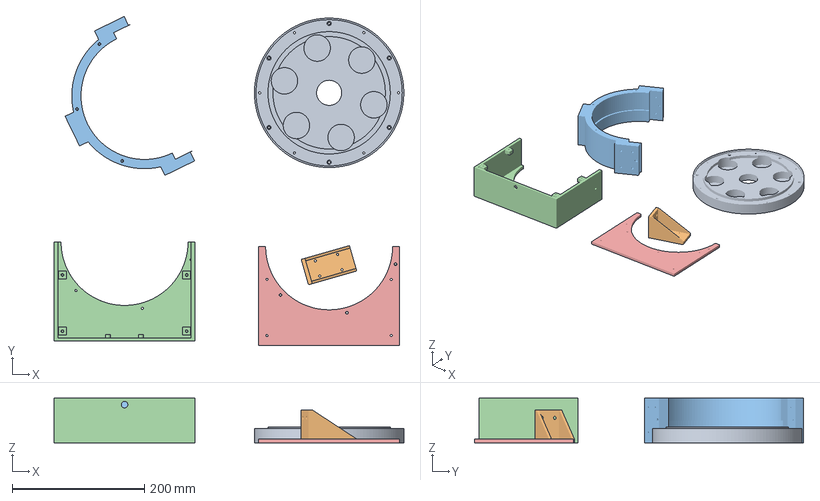
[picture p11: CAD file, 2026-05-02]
exports/xl_basis/helix-basis.3mf
528.9 x 497.6 x 68.0 mm
Helix_Base_Station_XXL-Stacking_Lager_Deckel_FLACH.stl
Helix_Base_Station_XXL-Wand_Flansch.stl
Helix_Base_Station_XXL-Basis_Gehaeuse_XXL.stl
Helix_Base_Station_XXL-Elektronik_Wartungs_Klappe.stl
Helix_Base_Station_XXL-Wartungsklappen_Boden.stl

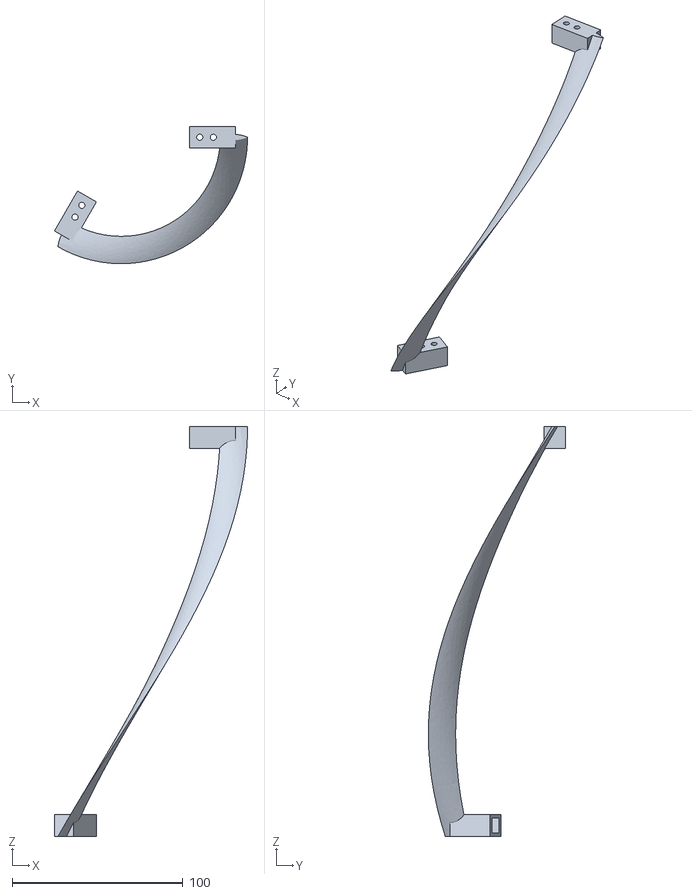
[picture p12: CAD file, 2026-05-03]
exports/flügel/gorlov/Gorlov_Modular_System-Gorlov_Blade_Modul_3.stl
113.0 x 80.4 x 240.0

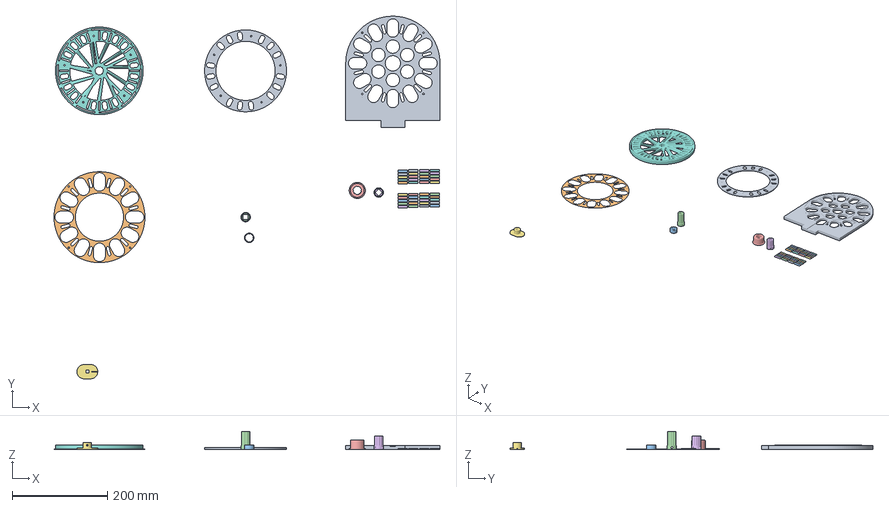
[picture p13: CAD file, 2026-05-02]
exports/generator/helix-generator.3mf
810.6 x 761.6 x 38.0 mm
Savonius_Kraftpaket_Generator-Magnet_Spacer_Kloetzchen.stl x 40
Savonius_Kraftpaket_Generator-_07_Stator_Schlitten_XXL.stl
Savonius_Kraftpaket_Generator-_08_Stator_Donut_Deckel_INSET.stl
Savonius_Kraftpaket_Generator-_11_Stator_Abstands_Spacer_10mm.stl
Savonius_Kraftpaket_Generator-_03_Clamp_Rotor_Stack_Mega_30mm.stl
Savonius_Kraftpaket_Generator-_02_Lager_Reduzierung_Unten.stl
Savonius_Kraftpaket_Generator-_01_Clamp_Lager_Unten.stl
Ortho_Kapsel_Spule1-Kapsel_Spule_Basis_Fix.stl
Helix_Kraftpaket_Generator-_05_Rotor_AeroFan_TANK_FINAL_Unten.stl
Helix_Kraftpaket_Generator-_04_Backplate_Ring_FLACH_Unten.stl

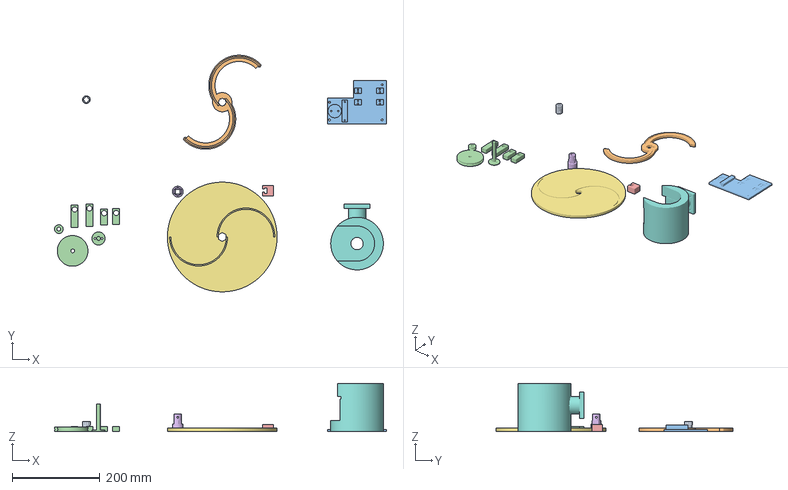
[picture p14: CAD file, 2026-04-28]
exports/middel-verbinder/HelixWindTower_allInOne.3mf
756.7 x 539.3 x 110.0 mm
Savonius_Coreless_Tower24-Zwischen_Vielzahn_Plug
Savonius_Coreless_Tower-Mittel_Verbinder_Skelett_FLACH.stl
Wickelmaschine_Basis_Raeder3-Maschinen_Basis_Modular.stl
Wickelmaschine_Basis_Raeder3-Turm_Kurbel_Vorne
Wickelmaschine_Basis_Raeder3-Schlitten_Drahtfuehrung_T_Form.stl
Savonius_Base_Station3-Adapter_Hex_Verbinder.stl
Savonius_Base_Station3-Start_Scheibe_FLACH.stl
Savonius_Base_Station3-Basis_Gehaeuse.stl

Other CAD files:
exports/tool/basis/Wickelmaschine_Basis_Raeder3-Turm_Kurbel_Hinten.stl
exports/tool/prooftool/magenet_spanner/Wickelmaschine_Magnet_Spanner6-Teil1_Basis_Mit_Bremse.stl
exports/tool/prooftool/Wickelmaschine_Ortho_Basis2-Z3_Spule_Out_10Z.stl
exports/tool/prooftool/zubehör/Wickelmaschine_Zubehoer_Komplett-Kurbel_Griff.stl
Savonius_Coreless_Tower_Energy_old.3mf
exports/flügel/gorlov/Gorlov_Modular_System-Gorlov_Blade_Modul_1.stl
exports/flügel/gorlov/Gorlov_Modular_System-Gorlov_Blade_Modul_2.stl
exports/flügel/gorlov/Gorlov_Modular_System-Skeleton_Strebe_248mm.stl
exports/generator/01_Clamp_Lager_Unten.stl
exports/generator/02_Lager_Reduzierung_Unten.stl
exports/generator/03_Clamp_Rotor_Stack_Mega_30mm.stl
exports/generator/04_Backplate_Ring_FLACH_Unten.stl
exports/generator/05_Rotor_AeroFan_TANK_FINAL_Unten.stl
exports/generator/07_Stator_Schlitten_XXL.stl
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

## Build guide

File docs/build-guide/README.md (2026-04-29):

# 📖 Bauanleitung / Build Guide

> **Helix Wind-Generator** — Vom 3D-Druck bis zum eigenen Strom

---

## Übersicht

Dieser Wind-Generator besteht aus 3 Hauptbaugruppen + optionalen Werkzeugen:

| # | Baugruppe | Beschreibung | Dauer* |
|---|---|---|:---:|
| 1 | [🗼 Helix-Turm](01_tower.md) | Modulare Helix-Flügel mit Stecksystem | ~6h |
| 2 | [⚡ Generator](02_generator.md) | XXL Axialfluss-Generator (Capsule-Spulen) | ~8h |
| 3 | [🏗️ XXL Basis-Station](03_base_station.md) | 220mm Gehäuse mit Lager und Wartungsklappe | ~4h |
| 4 | [🔧 Endmontage](04_final_assembly.md) | Alles zusammenbauen und testen | ~2h |
| 5 | [🛠️ Werkzeuge](05_tools.md) | Wickelmaschine, Magnet-Puffer, Easy-Tool | ~3h |

*\* Reine Montagezeit ohne Druckzeit*

---

## Bevor du anfängst

### Drucker-Anforderungen
- **Bauraum**: mindestens 256×256×256mm (z.B. Bambu Lab P1S, X1C)
- **Material**: PETG empfohlen (UV- und wetterbeständig!)
- **Düse**: 0.4mm Standard
- **Schichthöhe**: 0.2mm

### Werkzeuge
- [ ] Lötkolben mit feiner Spitze (für Einschmelzmuttern)
- [ ] Inbusschlüssel 2.5mm (für M3 Schrauben)
- [ ] Multimeter (für Spulen-Test)
- [ ] Sekundenkleber (Backup für Magnete)
- [ ] Kabelbinder

### Sicherheitshinweise

> ⚠️ **MAGNETE**: Neodym-Magnete (N52) sind extrem stark! Finger können eingeklemmt werden. Von Elektronik und Herzschrittmachern fernhalten.

> ⚠️ **LÖTKOLBEN**: Einschmelzmuttern werden bei ~250°C eingesetzt. Verbrennungsgefahr!

> ⚠️ **HÖHE**: Der Turm wird am Baum montiert. Arbeite NIE alleine bei der Montage in der Höhe.

---

## Empfohlene Reihenfolge

```
1. Drucke alle Teile (siehe BOM → docs/bom/master_bom.md)
2. Baue den Turm (Anleitung 01)
3. Wickle die Spulen und baue den Generator (Anleitung 02)  
4. Baue die Basis-Station (Anleitung 03)
5. Endmontage und erster Test (Anleitung 04)
```

---

## Vollständige Stückliste

→ Siehe [📋 Stückliste / BOM](../bom/master_bom.md) für alle benötigten Teile.

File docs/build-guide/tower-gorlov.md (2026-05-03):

# 🌀 Bauanleitung: Gorlov Helical-Turm

> Der Gorlov-Rotor ist die eleganteste Lösung: die gleiche Auftriebsgeometrie wie der Darrieus, aber mit 120° Helixdrall über die Höhe — dadurch startet er selbst, läuft ohne Drehmomentschwankungen und erreicht ~32% Wirkungsgrad.

**Aerodynamisches Prinzip**: Lift-Drag-Hybrid | **TSR**: 2,0–3,0 | **Cp**: ~32% | **Selbstanlaufend**: ✅ Ja

---

## Benötigte Teile (pro Etage)

- [ ] 3× Gorlov Helical Blade (TWR-GOR-01)
- [ ] 1× Gorlov Connector Ring (TWR-GOR-RING)
- [ ] 1× Vielzahn-Plug (TWR-PLUG-01)
- [ ] 4× M3 Einschmelzmutter (F-M3-HI)
- [ ] 4× M3×8 Madenschraube (F-M3x8-MDS)

### Zusätzlich für den kompletten Turm
- [ ] 1× Vierkant-Achse 10×10mm, Länge je nach Etagenanzahl (A-SQ10)

**Quellcode**: `src/leaf/gorlov_leaf.py`

---

## Schritt 1: Gorlov-Flügel drucken

### Flügelprofil
Das Gorlov-Blatt ist ein **bikonvexes, symmetrisches Tragflächenprofil** mit 120° Helixdrall über 240mm Höhe:
- Profil: Oberer Bogen (−8mm, 0) über (0, +1,7mm) bis (8mm, 0); unterer Bogen gespiegelt
- Sehne: 16mm | Dicke: 3,4mm | 48 Loft-Schritte

### Druckeinstellungen
| Parameter | Wert |
|---|---|
| Material | **CF-Nylon oder PLA-CF** |
| Schichthöhe | **0,15mm** (Pflicht für Profilgenauigkeit!) |
| Füllung | 40% |
| Wände | 4 |
| Stützstruktur | ❌ Nein — Helixform ist selbsttragend |
| Ausrichtung | Stehend (Höhe = Z-Achse) |

### Durchführung
1. Lade `exports/gorlov/Gorlov_Blade.stl` in deinen Slicer
2. Flügel stehend platzieren — die 120° Helix ist entlang der Z-Achse
3. **Kein Support nötig**: Die kontinuierliche Helixgeometrie trägt sich selbst
4. Drucke 3 Stück pro Etage
5. Am Blatt-Ring-Übergang Wände auf 5+ erhöhen (höchste Belastungszone)

> 💡 **TIPP**: 0,15mm Schichthöhe ist bei diesem Profil kein Luxus — die 3,4mm dicke Profilkante ist bei 0,3mm Schichten nicht mehr aerodynamisch korrekt. Das CF-Nylon kompensiert den Mehraufwand mit überlegener Festigkeit unter Schubbelastung.

> ⚠️ **ACHTUNG**: Die Blatt-Ring-Verbindung trägt den vollen Biegeanteil der Zentrifugalkraft bei Drehzahl. Prüfe nach dem Druck auf Delaminierung an dieser Stelle. Schwacher Verbund = Blattversagen bei Sturm.

---

## Schritt 2: Connector Ring drucken

Der Connector Ring schließt oben und unten die 3 Gorlov-Blätter zusammen und überträgt die Kraft auf den Vielzahn-Plug.

### Druckeinstellungen
| Parameter | Wert |
|---|---|
| Material | PLA-CF |
| Schichthöhe | 0,2mm |
| Füllung | 60% |
| Wände | 5 |
| Ausrichtung | Flach (Ring-Ebene = XY) |

### Abmessungen Ring
- Außenradius: 72mm | Innenbohrung: 13mm (Naben-Freistich)
- Vielzahn-Splineaufnahme am Bodenring: 12 Zähne, R9,0/R7,8, +0,2mm Spiel

### Durchführung
1. Lade `exports/gorlov/Gorlov_ConnectorRing.stl`
2. Ring flach auf dem Bett platzieren
3. Drucke 2 Stück pro Etage (oben + unten)
4. Überprüfe die Blattaufnahme-Slots auf scharfe Kanten — bei Bedarf mit 400er Schleifpapier entgraten

---

## Schritt 3: Vielzahn-Plug drucken + bestücken

Identisch mit allen anderen Rotortypen — das Vielzahn-Interface ist einheitlich.

### Druckeinstellungen
| Parameter | Wert |
|---|---|
| Material | PETG oder PLA-CF |
| Füllung | 60% |
| Wände | 4 |

### Einschmelzmuttern einsetzen
1. Lötkolben auf **250°C** vorheizen
2. 4× M3 Einschmelzmutter aufnehmen
3. Langsam und gerade in die Kragen-Taschen eindrücken
4. Bündig mit der Oberfläche abschließen lassen

> ⚠️ **ACHTUNG**: Nicht nachdrücken sobald die Mutter sitzt — das verdrängt Schmelzgrat in das Gewinde.

---

## Schritt 4: Zusammenbau einer Etage

1. **Bodenring einlegen**: Unteren Connector Ring auf die Arbeitsflä­che legen, Vielzahn-Seite nach unten
2. **Flügel einsetzen**: Alle 3 Gorlov-Flügel gleichzeitig in die Ring-Slots führen — exakt 120° versetzt
3. **Topring aufsetzen**: Oberen Connector Ring auf die Blattenden drücken und in die Slots rasten
4. **Plug einsetzen**: Vielzahn-Plug durch Bodenring und Achsloch des oberen Rings führen
5. **Achse durchschieben**: Vierkant-Achse durch Plug und alle Ringe schieben
6. **Madenschrauben anziehen**: 4× M3×8 im Kragen festziehen

> 💡 **TIPP**: Die Blätter können beim gleichzeitigen Einsetzen aller 3 leicht verklemmen. Starte von oben: oberen Ring leicht geneigt aufsetzen, ersten Flügel rasten, dann 120° weiterdrehen für den zweiten, nochmals 120° für den dritten. Dann Bodenring aufdrücken.

---

## Schritt 5: Etagen stapeln

1. Fertige Etage auf die Achse schieben
2. Nächste Etage aufsetzen — der Connector Ring der oberen Etage sitzt direkt auf dem der unteren
3. Plug der oberen Etage einsetzen und verschrauben
4. Wiederholen bis zur gewünschten Turmhöhe

> 💡 **TIPP**: Beim Gorlov-Rotor können die Etagen alle gleich ausgerichtet werden — der 120°-Drall jedes Blatts sorgt selbst dafür, dass sich zu jedem Zeitpunkt immer Blattabschnitte in günstiger Auftriebsposition befinden. Kein Versatz zwischen den Etagen nötig (anders als beim Darrieus H).

> 💡 **TIPP**: 3–4 Etagen sind ideal. Die Gorlov-Geometrie entfaltet ihren Vorteil (kein Drehmomentruckeln) besonders bei 3+ Etagen mit versetzter Blattphase.

---

## Vergleich mit anderen Rotortypen

| Eigenschaft | Gorlov (dieses Blatt) | Darrieus H | Helix Savonius |
|---|---|---|---|
| Wirkungsgrad Cp | **~32%** | ~28% | ~18% |
| Selbstanlaufend | ✅ Ja | ❌ Nein | ✅ Ja |
| Drehmomentrippel | **Keiner** | Hoch | Mittel |
| Druckschwierigkeit | Mittel-Hoch | Hoch | Einfach |
| Windbereich | Konstant/stark | Konstant | Böig/schwach |

---

## ✅ Fertig!

Dein Gorlov-Turm ist fertig. Teste die Rotation von Hand — er sollte extrem smooth laufen, ohne spürbare Drehmomentschwankungen. Wenn du ein leichtes "Anhalten und Weiterlaufen" bei einer Position spürst, ist ein Blatt falsch ausgerichtet oder der Ring klemmt.

**Weiter mit**: [⚡ Generator-Bauanleitung](02_generator.md)

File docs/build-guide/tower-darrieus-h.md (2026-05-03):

# 🗼 Bauanleitung: Darrieus H-Rotor

> Der Darrieus H-Rotor erzeugt seinen Antrieb ausschließlich über aerodynamischen Auftrieb — wie ein Flugzeugflügel, das sich dreht. Er startet nicht selbst, erreicht aber mit TSR 3–4 die höchsten Wirkungsgrade aller fünf Rotorprinzipien in diesem Projekt.

---

## Benötigte Teile

- [ ] 3× Tragflügel-Blatt (TWR-DAR-01)
- [ ] 1× Naben-Ring (TWR-DAR-HUB)
- [ ] 1× Deckscheibe oben (TWR-DAR-DISC-TOP)
- [ ] 1× Bodenplatte mit Vielzahn-Loch (TWR-DAR-DISC-BOT)
- [ ] 1× Vielzahn-Plug (TWR-PLUG-01)
- [ ] 6× M3 Einschmelzmutter (F-M3-HI)
- [ ] 6× M3×8 Madenschraube (F-M3x8-MDS)

### Zusätzlich für den kompletten Turm
- [ ] 1× Vierkant-Achse 10×10mm, Länge je nach Etagenanzahl (A-SQ10)

---

## Schritt 1: Tragflügel drucken

### Profil-Geometrie
| Parameter | Wert |
|---|---|
| Profiltyp | NACA-ähnlich, symmetrisch |
| Gesamttiefe (Chord) | 20 mm |
| Dicke | 4 mm |
| Nase | Halbzylinder Ø4mm |
| Heck | Halbzylinder Ø2.2mm bei Chord−1.8mm |
| Körper | 15.4×4mm Box, 1.2mm versetzt |
| Blattlänge | 240 mm |

### Druckeinstellungen
| Parameter | Wert |
|---|---|
| Material | PLA-CF |
| Schichthöhe | **0.1mm** (!!) |
| Füllung Streben | 100% |
| Füllung Blattkörper | 40% |
| Wände | 4 |
| Stützstruktur | ❌ Nein |
| Ausrichtung | Stehend (Länge = Z-Achse) |

### Durchführung
1. Lade `exports/generator/darrieus_h/TWR-DAR-01.stl` in deinen Slicer
2. Blatt stehend auf dem Druckbett platzieren — Längsachse zeigt nach oben
3. **Kein Support nötig!** Das Profil ist bei stehender Ausrichtung selbsttragend
4. Schichthöhe auf **0.1mm** einstellen — kein Kompromiss!
5. Drucke 3 Stück

> ⚠️ **ACHTUNG**: Die 0.1mm Schichthöhe ist zwingend. Gröbere Schichten zerstören die aerodynamische Genauigkeit des Profils und reduzieren den Wirkungsgrad spürbar.

> ⚠️ **ACHTUNG**: Die horizontalen Streben müssen mit **100% Infill** gedruckt werden — sie tragen die vollen Biegekräfte aus der Zentrifugalkraft bei Betriebsdrehzahl.

> 💡 **TIPP**: Alle drei Blätter passen gleichzeitig auf ein 256×256mm Druckbett. Prüfe die Ausrichtung im Slicer sorgfältig vor dem Start.

---

## Schritt 2: Naben-Ring drucken

### Druckeinstellungen
| Parameter | Wert |
|---|---|
| Material | PLA-CF |
| Schichthöhe | 0.2mm |
| Füllung | 100% |
| Wände | 4 |
| Stützstruktur | ❌ Nein |
| Ausrichtung | Flach (Ring-Ebene = XY) |

### Durchführung
1. Lade `exports/generator/darrieus_h/TWR-DAR-HUB.stl`
2. Flach auf dem Druckbett platzieren
3. 100% Infill für maximale Knotenfestigkeit an den Streben-Ansätzen
4. Naben-Radius beträgt 12mm — Mittelloch auf korrekte Achse prüfen

---

## Schritt 3: Deckscheiben drucken

### Druckeinstellungen (für beide Scheiben identisch)
| Parameter | Wert |
|---|---|
| Material | PLA-CF |
| Schichthöhe | 0.2mm |
| Füllung | 100% |
| Wände | 4 |
| Stützstruktur | ❌ Nein |
| Ausrichtung | Flach (Scheibenebene = XY) |

### Durchführung
1. Lade `exports/generator/darrieus_h/TWR-DAR-DISC-TOP.stl` und `TWR-DAR-DISC-BOT.stl`
2. Beide Scheiben flach drucken
3. Die **Bodenplatte** (TWR-DAR-DISC-BOT) hat das Vielzahn-Loch (12 Zähne, R9.0/R7.8) — Ausrichtung vor dem Druck prüfen!

---

## Schritt 4: Vielzahn-Plug drucken + bestücken

### Druckeinstellungen
| Parameter | Wert |
|---|---|
| Material | PLA-CF |
| Füllung | 60% |
| Wände | 4 |

### Einschmelzmuttern einsetzen
1. Lötkolben auf **250°C** vorheizen
2. Einschmelzmutter mit der Lötkolben-Spitze aufnehmen
3. Langsam und gerade in die Taschen des Plugs eindrücken
4. Bündig mit der Oberfläche abschließen lassen

> ⚠️ **ACHTUNG**: Die Muttern werden heiß! Nicht mit Fingern berühren. Lötkolben-Spitze nach dem Einsetzen sofort entfernen, nicht nachdrücken.

---

## Schritt 5: Zusammenbau

1. **Bodenplatte positionieren**: TWR-DAR-DISC-BOT flach auf die Arbeitsfläche legen, Vielzahn-Loch nach oben
2. **Blätter einsetzen**: Alle drei Blätter (TWR-DAR-01) im 120°-Abstand an den Streben-Endpunkten des Naben-Rings einhängen — Nabenradius R=12mm
3. **Naben-Ring zentrieren**: TWR-DAR-HUB über die drei Blatt-Ansätze schieben und ausrichten
4. **Streben-Positionen prüfen**: Untere Streben bei 15% der Blattlänge (36mm), obere bei 85% (204mm) — beides vom Blattfuß gemessen
5. **Deckscheibe aufsetzen**: TWR-DAR-DISC-TOP auf die Oberkante der Blätter aufsetzen und bündig ausrichten
6. **Plug einsetzen**: TWR-PLUG-01 in das Vielzahn-Loch der Bodenplatte drücken
7. **Achse durchschieben**: Vierkant-Achse durch Plug und Bodenplatte führen
8. **Madenschrauben anziehen**: 6× M3×8 Madenschrauben festziehen

> 💡 **TIPP**: Die 12-Zahn Vielzahn-Kupplung erlaubt 30°-Rastungen. Nutze das, um den Darrieus-Rotor optimal zur Helix-Etage darunter zu versetzt zu montieren.

---

## Schritt 6: Anlaufverhalten verstehen

> 💡 **TIPP**: Der Darrieus H-Rotor startet **nicht selbst**. Er benötigt einen kurzen Anschubs per Hand oder kurzen Motor-Impuls bei schwachem Wind. Sobald er über TSR = 1 beschleunigt hat, übernimmt der aerodynamische Auftrieb vollständig — ab da läuft er sehr effizient.

| Betriebspunkt | Wert |
|---|---|
| Selbststart | ❌ Nein |
| Optimale TSR | 3–4 |
| Anlaufhilfe | Kurzer Handanstoß oder Motor-Impuls |
| Wirkungsgrad-Peak | Höchster aller 5 Rotorprinzipien |

---

## Quellskript

```
src/leaf/darrieus_h_leaf.py
```

---

## ✅ Fertig!

Der Darrieus H-Rotor sollte sich jetzt leichtgängig von Hand drehen lassen. Gib ihm einen Schwung — er sollte mehrere Umdrehungen aus dem Impuls freilaufen. Wenn er sofort abbremst, Lagerreibung und Achspassung prüfen.

**Weiter mit**: [🌀 Gorlov Helical Rotor](tower-gorlov.md)

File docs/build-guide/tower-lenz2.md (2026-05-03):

# 🗼 Bauanleitung: Lenz2-Turm

> Der Lenz2-Rotor kombiniert das hohe Anlaufdrehmoment des Savonius mit Vortex-Auftrieb am Öffnungsrand — 3 Flügel à 210° Bogenwinkel ergeben eine kompakte Turbine mit überraschendem Wirkungsgrad für Stadtwind.

---

## Benötigte Teile (pro Etage)

- [ ] 3× Lenz2-Flügel (TWR-LEN-01)
- [ ] 1× Mittelverbinder Skelett 3-Arm (TWR-CONN-03)
- [ ] 1× Vielzahn-Plug (TWR-PLUG-01)
- [ ] 4× M3 Einschmelzmutter (F-M3-HI)
- [ ] 4× M3×8 Madenschraube (F-M3x8-MDS)

### Zusätzlich für den kompletten Turm

- [ ] 1× Vierkant-Achse 10×10mm, Länge je nach Etagenanzahl (A-SQ10)

---

## Schritt 1: Lenz2-Flügel drucken

### Druckeinstellungen

| Parameter | Wert |
|---|---|
| Material | PETG oder PLA-CF |
| Schichthöhe | 0.2mm |
| Füllung | 30% |
| Wände | 3 |
| Stützstruktur | ❌ Nein |
| Ausrichtung | Stehend (Höhe 240mm = Z-Achse) |

### Durchführung

1. Lade `exports/middel-verbinder/Lenz2_Fluegel.stl` in deinen Slicer
2. Flügel stehend auf dem Druckbett platzieren — die 240mm Blatthöhe ist die Z-Achse
3. Kein Support nötig — der 210°-Bogen ist geometrisch selbsttragend in vertikaler Ausrichtung
4. Drucke **3 Stück** pro Etage (alle Flügel sind identisch)

> 💡 **TIPP**: PLA-CF (Carbon-gefülltes PLA) erzeugt besonders steife Flügel bei geringem Gewicht — empfohlen für Türme ab 4 Etagen. Standard-PETG reicht für 1–3 Etagen vollständig aus. Innenwandradius: ≈38.5mm (66mm × 0.62 − 2.4mm Wandstärke).

---

## Schritt 2: Mittelverbinder 3-Arm drucken

### Druckeinstellungen

| Parameter | Wert |
|---|---|
| Material | PETG |
| Schichthöhe | 0.2mm |
| Füllung | 40% |
| Wände | 4 |
| Stützstruktur | ❌ Nein |
| Ausrichtung | Flach (8mm Höhe = Z-Achse) |

### Durchführung

1. Lade `exports/middel-verbinder/Mittel_Verbinder_Skelett_FLACH_3arm.stl`
2. Flach drucken — die 8mm Kappenhöhe ist die Z-Achse
3. Der 3-Arm-Verbinder hat **3 Flügelrillen im 120°-Raster** anstelle der 2 Rillen beim Standard-Verbinder
4. Hoher Infill (40%) für strukturelle Festigkeit an allen drei Armen!

> ⚠️ **ACHTUNG**: Den 2-Arm-Verbinder (TWR-CONN-01) der Helix- und Savonius-Variante **nicht** für den Lenz2 verwenden! Der 3-Arm-Verbinder (TWR-CONN-03) hat ein anderes Rillen-Raster.

---

## Schritt 3: Vielzahn-Plug drucken + bestücken

### Druckeinstellungen

| Parameter | Wert |
|---|---|
| Material | PETG |
| Füllung | 60% |
| Wände | 4 |

### Einschmelzmuttern einsetzen

1. Lötkolben auf **250°C** vorheizen
2. Einschmelzmutter mit der Lötkolben-Spitze aufnehmen
3. Langsam und gerade in die 4 Taschen des Kragens eindrücken
4. Bündig mit der Oberfläche abschließen lassen

> ⚠️ **ACHTUNG**: Die Muttern werden heiß! Nicht mit Fingern berühren. Lötkolben-Spitze nach dem Einsetzen sofort entfernen, nicht nachdrücken.

---

## Schritt 4: Zusammenbau einer Etage

1. **Ersten Flügel einstecken**: Flügel in eine der drei Rillen des Verbinders stecken — die Becheröffnung (210°-Bogen) zeigt radial nach außen
2. **Zweiten Flügel einstecken**: Um **120°** versetzt in die zweite Rille stecken, Öffnung ebenfalls radial nach außen
3. **Dritten Flügel einstecken**: Um weitere **120°** versetzt (also 240° zum ersten) in die dritte Rille stecken
4. **Plug einsetzen**: Vielzahn-Plug (12-Zahn, R9.0/R7.8) in das zentrale Loch des Verbinders drücken
5. **Achse durchschieben**: Vierkant-Achse (10×10mm) durch Plug und Verbinder führen
6. **Madenschrauben anziehen**: 4× M3×8 Madenschrauben im Kragen gleichmäßig festziehen

> 💡 **TIPP**: Alle drei Flügel sind identisch — keine Spiegelvarianten wie beim Savonius. Kontrolliere in der Draufsicht, dass die drei Öffnungen gleichmäßig im Kreis verteilt sind und alle in dieselbe Umlaufrichtung zeigen (Schaufelöffnung vorne, Rücken hinten).

---

## Schritt 5: Etagen stapeln

1. Nächste Etage von oben aufsetzen
2. Flügel der oberen Etage in die **oberen** Rillen des unteren Verbinders stecken
3. Verbinder der oberen Etage von oben aufsetzen
4. Plug einsetzen und verschrauben
5. Wiederholen bis gewünschte Höhe erreicht

> 💡 **TIPP**: Die 210°-Öffnung ist breiter als ein Halbkreis — sie erzeugt an der Eintrittskante einen Vortex, der Auftrieb über reinen Strömungswiderstand hinaus liefert. Dieser Effekt wirkt über die gesamte Blatthöhe und steigert den Wirkungsgrad gegenüber klassischem Savonius spürbar.

---

## Technische Referenz

| Merkmal | Wert |
|---|---|
| Flügelprofil | Asymmetrischer Bogen, 210° Öffnungswinkel |
| Flügelhöhe | 240mm |
| Außenradius | 66mm |
| Innenradius | ≈38.5mm (66mm × 0.62 − 2.4mm) |
| Wandstärke | 2.4mm |
| Flügel pro Etage | 3 (identisch, 120° versetzt) |
| Verdrehung Etage zu Etage | Optional (0° oder 60° für bessere Windabdeckung) |
| Vielzahn | 12 Zähne, R9.0/R7.8 |
| Quellskript | `src/leaf/lenz2_leaf.py` |

---

## ✅ Fertig!

Dein Lenz2-Turm sollte jetzt frei auf der Achse rotieren. Teste den Lauf von Hand — er sollte smooth und ohne Unwucht drehen. Schon bei leichtem Wind (ab ca. 2 m/s) sollte der Rotor selbstständig anlaufen, ohne Anstoßen.

---

**Weiter mit**: [⚡ Generator-Bauanleitung](02_generator.md)

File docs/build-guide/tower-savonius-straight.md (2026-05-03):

# 🗼 Bauanleitung: Savonius-Turm (Straight)

> Der Savonius-Rotor ist der einfachste Windrotor — zwei halbzylindrische Flügel erzeugen durch Schaufelsog hohe Anlaufdrehmomente bei niedrigen Windgeschwindigkeiten. Kein Anlaufstrom, kein Anlaufproblem.

---

## Benötigte Teile (pro Etage)

- [ ] 1× Savonius-Flügel A (TWR-STR-01)
- [ ] 1× Savonius-Flügel B (TWR-STR-02)
- [ ] 1× Mittelverbinder Skelett (TWR-CONN-01)
- [ ] 1× Vielzahn-Plug (TWR-PLUG-01)
- [ ] 4× M3 Einschmelzmutter (F-M3-HI)
- [ ] 4× M3×8 Madenschraube (F-M3x8-MDS)

### Zusätzlich für den kompletten Turm

- [ ] 1× Vierkant-Achse 10×10mm, Länge je nach Etagenanzahl (A-SQ10)

---

## Schritt 1: Savonius-Flügel drucken

### Druckeinstellungen

| Parameter | Wert |
|---|---|
| Material | PETG |
| Schichthöhe | 0.2mm |
| Füllung | 20% |
| Wände | 3 |
| Stützstruktur | ❌ Nein |
| Ausrichtung | Flach (Halbzylinder-Öffnung zeigt nach oben) |

### Durchführung

1. Lade `exports/middel-verbinder/Savonius_Straight_Fluegel_A.stl` in deinen Slicer
2. Flügel A flach auf dem Druckbett platzieren — die gebogene Außenseite liegt unten, die offene Seite zeigt nach oben
3. Wiederhole für `Savonius_Straight_Fluegel_B.stl` (Spiegelvariante)
4. Kein Support nötig — der gerade halbzylindrische Querschnitt ist vollständig selbsttragend
5. Drucke je 1× Flügel A und 1× Flügel B pro Etage

> 💡 **TIPP**: Flügel A und B sind Spiegelbilder voneinander. Beide können gleichzeitig auf dem Druckbett gedruckt werden. Die Wandstärke beträgt 2.4mm — halte Schichtlinienmuster (Perimeter) parallel zur Kurve für maximale Biegesteifigkeit.

---

## Schritt 2: Mittelverbinder drucken

### Druckeinstellungen

| Parameter | Wert |
|---|---|
| Material | PETG |
| Schichthöhe | 0.2mm |
| Füllung | 40% |
| Wände | 4 |
| Stützstruktur | ❌ Nein |
| Ausrichtung | Flach (8mm Höhe = Z-Achse) |

### Durchführung

1. Lade `exports/middel-verbinder/Mittel_Verbinder_Skelett_FLACH.stl`
2. Flach drucken — die 8mm Kappenhöhe ist die Z-Achse
3. Hoher Infill (40%) für strukturelle Festigkeit an den Flügelrillen!

> 💡 **TIPP**: Derselbe Verbinder wird für alle Turmvarianten (Helix, Savonius, Lenz2) verwendet. Du kannst vorhandene Bestände wiederverwenden.

---

## Schritt 3: Vielzahn-Plug drucken + bestücken

### Druckeinstellungen

| Parameter | Wert |
|---|---|
| Material | PETG |
| Füllung | 60% |
| Wände | 4 |

### Einschmelzmuttern einsetzen

1. Lötkolben auf **250°C** vorheizen
2. Einschmelzmutter mit der Lötkolben-Spitze aufnehmen
3. Langsam und gerade in die 4 Taschen des Kragens eindrücken
4. Bündig mit der Oberfläche abschließen lassen

> ⚠️ **ACHTUNG**: Die Muttern werden heiß! Nicht mit Fingern berühren. Lötkolben-Spitze nach dem Einsetzen sofort entfernen, nicht nachdrücken.

---

## Schritt 4: Zusammenbau einer Etage

1. **Flügel A einstecken**: Flügel A in eine der beiden Rillen des Verbinders stecken (Öffnung zeigt nach innen zur Achse)
2. **Flügel B einstecken**: Flügel B um **180°** versetzt in die gegenüberliegende Rille stecken — die Öffnungen zeigen aufeinander zu und bilden das klassische S-Profil
3. **Plug einsetzen**: Vielzahn-Plug (12-Zahn, R9.0/R7.8) in das zentrale Loch des Verbinders drücken
4. **Achse durchschieben**: Vierkant-Achse (10×10mm) durch Plug und Verbinder führen
5. **Madenschrauben anziehen**: 4× M3×8 Madenschrauben im Kragen gleichmäßig festziehen

> 💡 **TIPP**: Kontrolliere vor dem Festschrauben, dass die Schaufelöffnungen exakt 180° versetzt sind und das S-Profil in der Draufsicht symmetrisch wirkt. Unsymmetrie verursacht Unwucht und Vibration.

---

## Schritt 5: Etagen stapeln

1. Nächste Etage von oben aufsetzen
2. Flügel der oberen Etage in die **oberen** Rillen des unteren Verbinders stecken
3. Verbinder der oberen Etage von oben aufsetzen
4. Plug einsetzen und verschrauben
5. Wiederholen bis gewünschte Höhe erreicht

> 💡 **TIPP**: **Kein Twist zwischen den Etagen!** Beim Savonius-Straight bleiben alle Etagen gleich ausgerichtet (im Gegensatz zur Helix-Variante). Das erzeugt den klassischen Savonius-Schaufelzug, bei dem immer eine Schaufel optimal dem Wind zugewandt ist.

---

## Technische Referenz

| Merkmal | Wert |
|---|---|
| Flügelprofil | Halbzylinder, 180° Bogen |
| Flügelhöhe | 240mm |
| Flügelradius | 66mm |
| Wandstärke | 2.4mm |
| Flügel pro Etage | 2 (A + B, 180° versetzt) |
| Verdrehung Etage zu Etage | 0° (keine — alle gleich) |
| Vielzahn | 12 Zähne, R9.0/R7.8 |
| Quellskript | `src/leaf/savonius_straight_leaf.py` |

---

## ✅ Fertig!

Dein Savonius-Turm sollte jetzt frei auf der Achse rotieren. Teste den Lauf von Hand — er sollte smooth und ohne Unwucht drehen. Bei leichtem Windhauch sollte er sofort anlaufen, ohne Anstoßen.

---

**Weiter mit**: [⚡ Generator-Bauanleitung](02_generator.md)

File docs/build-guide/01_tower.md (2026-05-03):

# 🗼 Bauanleitung: Helix-Turm

> Der Turm besteht aus modularen Etagen. Jede Etage hat 2 Helix-Flügel, einen Mittelverbinder und einen Vielzahn-Plug. Stapele so viele Etagen wie du möchtest!

---

## Benötigte Teile (pro Etage)

- [ ] 2× Helix-Flügel (TWR-LEAF-01)
- [ ] 1× Mittelverbinder Skelett (TWR-CONN-01)
- [ ] 1× Vielzahn-Plug (TWR-PLUG-01)
- [ ] 4× M3 Einschmelzmutter (F-M3-HI)
- [ ] 4× M3×8 Madenschraube (F-M3x8-MDS)

### Zusätzlich für den kompletten Turm
- [ ] 1× Vierkant-Achse 10×10mm, Länge je nach Etagenanzahl (A-SQ10)

---

## Schritt 1: Flügel drucken

### Druckeinstellungen
| Parameter | Wert |
|---|---|
| Material | PETG |
| Schichthöhe | 0.2mm |
| Füllung | 15% |
| Wände | 3 |
| Stützstruktur | ❌ Nein |
| Ausrichtung | Stehend (Höhe = Z-Achse) |

### Durchführung
1. Lade `exports/middel-verbinder/Coreless_Helix_Fluegel.stl` in deinen Slicer
2. Platziere den Flügel stehend auf dem Druckbett
3. **Kein Support nötig!** Die Helix-Form ist selbsttragend
4. Drucke 2 Stück pro Etage

> 💡 **TIPP**: Beide Flügel können gleichzeitig auf dem Druckbett gedruckt werden (sie sind identisch, die 180°-Drehung erfolgt bei der Montage).

---

## Schritt 2: Mittelverbinder drucken

### Druckeinstellungen
| Parameter | Wert |
|---|---|
| Material | PETG |
| Schichthöhe | 0.2mm |
| Füllung | 40% |
| Wände | 4 |
| Stützstruktur | ❌ Nein |
| Ausrichtung | Flach (8mm Höhe = Z-Achse) |

### Durchführung
1. Lade `exports/middel-verbinder/Mittel_Verbinder_Skelett_FLACH.stl`
2. Flach drucken — die 8mm Kappenhöhe ist die Z-Achse
3. Hoher Infill (40%) für strukturelle Festigkeit!

---

## Schritt 3: Vielzahn-Plug drucken + bestücken

### Druckeinstellungen
| Parameter | Wert |
|---|---|
| Material | PETG |
| Füllung | 60% |
| Wände | 4 |

### Einschmelzmuttern einsetzen
1. Lötkolben auf **250°C** vorheizen
2. Einschmelzmutter mit der Lötkolben-Spitze aufnehmen
3. Langsam und gerade in die 4 Taschen des Kragens eindrücken
4. Bündig mit der Oberfläche abschließen lassen

> ⚠️ **ACHTUNG**: Die Muttern werden heiß! Nicht mit Fingern berühren. Lötkolben-Spitze nach dem Einsetzen sofort entfernen, nicht nachdrücken.

---

## Schritt 4: Zusammenbau einer Etage

1. **Flügel einstecken**: Beide Flügel um 180° versetzt in die unteren Rillen des Verbinders stecken
2. **Plug einsetzen**: Vielzahn-Plug in das zentrale Loch des Verbinders drücken
3. **Achse durchschieben**: Vierkant-Achse durch Plug und Verbinder führen
4. **Madenschrauben anziehen**: 4× M3×8 Madenschrauben im Kragen festziehen

> 💡 **TIPP**: Die 12-Zahn Vielzahn-Kupplung erlaubt 30°-Rastungen. Nutze das für die Helix-Verdrehung zwischen den Etagen!

---

## Schritt 5: Etagen stapeln

1. Nächste Etage von oben aufsetzen
2. Flügel der oberen Etage in die **oberen** Rillen des unteren Verbinders stecken
3. Verbinder der oberen Etage von oben aufsetzen
4. Plug einsetzen und verschrauben
5. Wiederholen bis gewünschte Höhe erreicht

> 💡 **TIPP**: Empfohlen sind 3–5 Etagen für eine gute Windausbeute bei handlicher Größe.

---

## ✅ Fertig!

Dein Turm sollte jetzt frei auf der Achse rotieren. Teste den Lauf von Hand — er sollte smooth und ohne Unwucht drehen.

---

## Rotor-Varianten (Landing-Page kompatibel)

Für die zusätzlichen Rotorprinzipien aus der interaktiven Landing-Page sind nun eigene FreeCAD-Skripte verfügbar:

- `src/leaf/savonius_straight_leaf.py`
- `src/leaf/lenz2_leaf.py`
- `src/leaf/darrieus_h_leaf.py`
- `src/leaf/gorlov_leaf.py`

### Hinweise
1. Alle Varianten nutzen `shared/parameters.json` als zentrale Parameterquelle.
2. Das Vielzahn-Interface bleibt identisch (`12 Zähne`, `R9.0/R7.8`) und ist kompatibel zur bestehenden Achse.
3. Druckprofil: PETG empfohlen für alle Blatt-Varianten (mind. 3 Wände, 20-30% Infill je nach Profil).

**Weiter mit**: [⚡ Generator-Bauanleitung](02_generator.md)

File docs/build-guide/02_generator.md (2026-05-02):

# ⚡ Bauanleitung: Aero-Fan Generator v3.0 (20-Pol)

> Sandwich-Generator mit 2 Aero-Fan Rotoren (Ø184mm), 12 Capsule-Spulen, Vielzahn-Clamp-System.
> Quelle: `src/generator/helix_generator.py` · Material: PLA-CF für Rotoren/Clamps, PETG für Stator

---

## Benötigte Druckteile

| ID | STL-Datei (exports/generator/) | Menge | Material | Infill |
|----|---|:-----:|---|:---:|
| XLG-ROT-01 | 09_Rotor_AeroFan_TANK_FINAL_Oben | 1 | PLA-CF | 30% |
| XLG-ROT-02 | 05_Rotor_AeroFan_TANK_FINAL_Unten | 1 | PLA-CF | 30% |
| XLG-BP-01 | 10_Backplate_Ring_FLACH_Oben | 1 | PLA-CF | 25% |
| XLG-BP-02 | 04_Backplate_Ring_FLACH_Unten | 1 | PLA-CF | 25% |
| XLG-STAT-01 | 07_Stator_Schlitten_XXL | 1 | PETG | 25% |
| XLG-STAT-02 | 08_Stator_Donut_Deckel_INSET | 1 | PETG | 20% |
| XLG-CLAMP-01 | 03_Clamp_Rotor_Stack_Mega_30mm | 1 | PLA-CF | 80% |
| XLG-CLAMP-02 | 01_Clamp_Lager_Unten | 1 | PLA-CF | 80% |
| XLG-CLAMP-03 | 13_Clamp_Lager_Oben | 1 | PLA-CF | 80% |
| XLG-REDUZ-01 | 02_Lager_Reduzierung_Unten | 1 | PLA-CF | 80% |
| XLG-REDUZ-02 | 14_Lager_Reduzierung_Oben | 1 | PLA-CF | 80% |
| XLG-SPACER-01 | 11_Stator_Abstands_Spacer_10mm | 1 | PETG | 100% |
| XLG-PLUG-01 | 15_Magnet_Spacer_Kloetzchen | 20 | PETG | 100% |

## Benötigte Kaufteile

- [ ] 20× Neodym-Magnet **20×5×3mm N52** (vernickelt)
- [ ] 12× M3 Einschmelzmutter Ø4.2×5mm (3 Clamps × 4)
- [ ] 5× M5×20 Senkkopfschraube (Backplate auf Rotor)
- [ ] 4× M3×8 Zylinderkopfschraube (Stator-Deckel)
- [ ] ~100m Kupferlackdraht Ø0.5mm

---

## Schritt 1: Clamps vorbereiten — Einschmelzmuttern

Alle 3 Universal-Clamps (XLG-CLAMP-01/02/03) haben je 4× M3 Einschmelzmuttern **radial** im Kragen.

1. Lötkolben auf ~250°C, Muttern von außen in die radialen Taschen eindrücken
2. Jede Mutter sitzt in einer 4.2mm Bohrung, bündig mit der Kragen-Außenfläche

> 💡 Die Muttern fixieren später Madenschrauben (M3×5) zum Klemmen auf der Vielzahn-Achse.

---

## Schritt 2: Magnete einsetzen

> ⚠️ **KRITISCH: Polarität!** Beide Rotoren müssen sich **anziehen** (N-Pol von Rotor Oben zu S-Pol von Rotor Unten).

1. Alle N-Pole mit Edding markieren, bevor du anfängst
2. Je 20 Magnete abwechselnd N/S in die Taschen (radial ausgerichtet, R=74mm)
3. **Magnet-Spacer** (XLG-PLUG-01, 20 Stk.) über jeden Magneten setzen — hält Magnete höhenbündig
4. Test: Rotor Oben und Unten gegenüberhalten → müssen sich **anziehen**

---

## Schritt 3: Backplate-Ringe montieren

1. **XLG-BP-01** auf **XLG-ROT-01** (Oben) aufsetzen
2. 5× M5×20 Senkkopfschrauben durch die Backplate → Rotor → Einschmelzmuttern (R=74mm, 72° Abstand)
3. Gleiches für **XLG-BP-02** + **XLG-ROT-02** (Unten)

> Die Backplate ist ein flacher Donut R62–86mm mit 15 Material-Einspar-Taschen — kein Plug-Array mehr.

---

## Schritt 4: Spulen wickeln (12 Stück)

### Capsule-Wickeldaten

| Parameter | Wert |
|---|---|
| Spulenform | Oval / Capsule |
| Außenmaß Tasche | 40.4×26.4mm |
| Innen-Kern | 22×8mm |
| Taschen-Tiefe | 6mm (+ 0.5mm Kragen oben) |
| Draht | Kupferlackdraht Ø0.5mm |
| Windungen | ~120–150 pro Spule |

> 💡 Verwende den **Komplex-Spooler** (1:24 Übersetzung) für gleichmäßige Lagen.
> Alternativ: **Easy-Tool** mit Akkuschrauber. → [05_tools.md](05_tools.md)

---

## Schritt 5: Stator bestücken und verdrahten

1. 12 Spulen in die Capsule-Taschen des **XLG-STAT-01** einsetzen (R=74mm, je 30° Abstand)
2. **3-Phasen Stern-Schaltung** verdrahten:
   - Phase A: Spulen 1, 4, 7, 10
   - Phase B: Spulen 2, 5, 8, 11
   - Phase C: Spulen 3, 6, 9, 12
3. Kabel durch den **Ring-Kanal** (R82–88mm, Z=6.5, 1mm tief) und den radialen Kabelkanal nach außen
4. **XLG-STAT-02** (Donut-Deckel, 1.5mm dünn) auflegen — passt bündig in die Lid-Pocket des Stators
5. 4× M3×8 durch Deckel-Bohrungen (R=91mm, 45° versetzt) anziehen

---

## Schritt 6: Aufbau auf der Achse

Reihenfolge auf der Vielzahn-Achse **von unten nach oben**:

```
Basis-Station (Lager)
  → XLG-REDUZ-01  (Lager-Reduzierung Unten, Pressfit Ø29.15mm)
  → XLG-CLAMP-02  (Clamp Lager Unten, 180° gespiegelt)
  → XLG-CLAMP-01  (Clamp Rotor-Stack, 30mm Plug nach oben)
  → XLG-ROT-02    (Rotor Unten, Magnete zeigen nach oben)
  → XLG-SPACER-01 (Stator-Abstands-Spacer, 10mm, Vielzahn-Loch)
  → XLG-STAT-01   (Stator-Schlitten, wird in Basis-Schlitz eingefahren)
  → XLG-ROT-01    (Rotor Oben, Magnete zeigen nach unten)
  → XLG-CLAMP-03  (Clamp Lager Oben)
  → XLG-REDUZ-02  (Lager-Reduzierung Oben, 180° gespiegelt)
  → Turm-Vielzahn-Plug (TWR-PLUG-01)
```

---

## Schritt 7: Funktionstest

1. Von Hand drehen → leichtgängig, kein Schleifen am Stator
2. Multimeter an die 3 Phasen-Ausgänge (Stern-Mittelpunkt als Null)
3. Bei flotter Handdrehung: **>3V AC** pro Phase erwartet

> ⚠️ **<1V**: Magnetpolarität oder Phasen-Verschaltung prüfen. Rotor Oben und Unten müssen sich **anziehen**.

---

## ✅ Fertig!

**Weiter mit**: [🏗️ XXL Basis-Station](03_base_station.md)

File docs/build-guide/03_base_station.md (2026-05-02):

# 🏗️ Bauanleitung: XXL Basis-Station v3.0 (68mm)

> Extrem flache 68mm Basis, Ø220mm. U-Form-Öffnung für Stator-Einschub, Führungslippe am Stacking-Deckel, abnehmbare Wartungsklappe mit PCB-Standoffs.
> Quelle: `src/base/helix_station.py`

---

## Benötigte Druckteile

| ID | STL-Datei (exports/xl_basis/) | Menge | Infill |
|----|---|:-----:|:---:|
| XL-HOUS-01  | Basis_Gehaeuse_XXL | 1 | 25% |
| XL-DECK-01  | Stacking_Lager_Deckel_FLACH | 1 | 40% |
| XL-FLNSH-01 | Wand_Flansch | 3 | 50% |
| XL-KLAP-01  | Elektronik_Wartungs_Klappe | 1 | 20% |
| XL-BODEN-01 | Wartungsklappen_Boden | 1 | 30% |

## Benötigte Kaufteile

- [ ] 1× Kegelrollenlager **29×50×15mm** (REAL GEMESSEN — kein Datenblatt!)
- [ ] 24× M3 Einschmelzmutter Ø4.2×5mm
- [ ] 6× M3×16 Senkkopfschraube (Wand-Flansch → Gehäuse)
- [ ] 6× M6×30 Senkkopfschraube (Flansch → Wand)
- [ ] 4× M3×12 Zylinderkopfschraube (Klappen-Boden)

---

## Schritt 1: Einschmelzmuttern ins Gehäuse

Das Gehäuse hat drei Flansch-Pads (rechts, links, hinten) und Deckel-Bohrungen.

### Flansch-Pads (je 4× pro Pad = 12×)
- 4× an jedem der 3 Pads bei Z=15mm und Z=53mm
- Einschmelzen von der geraden Außenfläche (bei X=±121.5mm bzw. Y=121.5mm)

### Deckel-Verschraubung (R=104mm, 15° versetzt, 12 Bohrungen)
- **Gerade Positionen** (i=0,2,4…): Insert sitzt bei Z=63–68mm (oben), gehört zum Gehäuse → **6× einschmelzen**
- **Ungerade Positionen** (i=1,3,5…): Insert sitzt bei Z=0–5mm (unten), gehört zum Gehäuse → **6× einschmelzen**

> 💡 Insgesamt ~24 Einschmelzmuttern im Gehäuse. Lötkolben 250°C, langsam und gerade eindrücken.

---

## Schritt 2: Kegelrollenlager einpressen

1. **Stacking-Deckel** (XL-DECK-01) flach auf Tisch legen — Lagertasche zeigt nach oben
2. Lagertasche ist **50.2mm** (= Lager 50mm + 0.2mm Toleranz)
3. Lager mit gleichmäßigem Druck einpressen — ggf. mit einer Schraubzwinge oder Presse
4. Lager muss **bündig** mit der oberen Fläche sitzen

> ⚠️ Nie auf den Innenring hämmern — nur auf den Außenring drücken!

---

## Schritt 3: Stator-Schlitten einfahren

Das Gehäuse hat eine **U-Form-Öffnung** (213mm breit) und einen **Stator-Schlitz** bei Z=25.8–34.2mm.

1. Stator-Schlitten (XLG-STAT-01) von vorne durch die Öffnung einschieben
2. In den Schlitz einfädeln — der Stator läuft auf R=99mm, der Schlitz ist 99.5mm Radius
3. Stator schiebt sich bis zur Mitte und rastet in der richtigen Position

> 💡 Der Stator-Schlitz ist 8.4mm hoch (Stator 9mm − 0.6mm Spiel). Er sitzt bündig bei Ø198mm.

---

## Schritt 4: Stacking-Deckel aufsetzen

1. Stacking-Deckel von oben auf das Gehäuse aufsetzen
2. Die **Führungslippe** (R96–110mm, 4mm hoch) zentriert den Deckel automatisch am Gehäuse-Innenrand
3. Der **Führungsring** (R85–95.5mm, 6mm tief) greift in den Stator-Radius ein
4. 12× M3×16 Senkkopfschrauben durch die Deckel-Bohrungen (R=104mm) in die Einschmelzmuttern des Gehäuses

---

## Schritt 5: Wand-Flansche montieren

Die Flansche (XL-FLNSH-01) verbinden die Basis mit der Wand/Träger.

1. 3× Wand-Flansch auf die 3 Pads aufsetzen (rechts, links, hinten)
2. Je 4× M3×16 Senkkopf durch den senkrechten Flansch-Steg in die Pad-Einschmelzmuttern
3. Je 2× M6×30 durch die waagerechten Löcher in die Wand/Träger

> 💡 Die Dreiecks-Rippen am Flansch tragen Last — Montage ohne diese Seite führt zu Bruch!

---

## Schritt 6: Elektronik-Wartungsklappe

Die Klappe schließt die U-Form-Öffnung vorne und enthält die Elektronik.

1. **PCB-Standoffs**: 4× innen an der Rückwand (±25mm, Z=20mm + 50mm)
2. Gleichrichter, Laderegler und Anschlussklemmen auf den Standoffs befestigen
3. Kabel durch die **Kabeldurchführung** (Ø10mm, Z=10mm) führen
4. Klappe in die Öffnung einschieben und mit 1× M3×16 pro Seite (Z=34mm) verriegeln
5. **Klappen-Boden** (XL-BODEN-01) von unten aufsetzen und mit 4× M3×12 an den Tabs verschrauben

---

## Schritt 7: Generator einsetzen

1. Lager-Reduzierung Unten (XLG-REDUZ-01) in den Innenring des Kegelrollenlagers einpressen
   - Schaft Ø29.15mm (= Lager-Innen 29mm + 0.15mm Pressfit)
   - Fase ermöglicht leichtes Einfädeln
2. Vielzahn-Achse von oben einführen, alle Generator-Komponenten von oben aufstecken
3. Von unten: Clamp Lager Unten aufschrauben (fixiert Position)

---

## ✅ Fertig!

**Weiter mit**: [🔩 Endmontage](04_final_assembly.md)

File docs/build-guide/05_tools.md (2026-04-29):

# 🔧 Bauanleitung: Werkzeuge

> Hier findest du die Anleitungen für die Wickel-Werkzeuge. Wähle dein Level!

---

## 🎯 Übersicht — Welches Werkzeug brauchst du?

| Level | Werkzeug | Beschreibung | Teile |
|:-----:|---|---|:-----:|
| ⭐ | [Easy-Tool](#-easy-tool) | Akkuschrauber-Aufsatz | 2 |
| ⭐⭐ | [First Spooler](#-first-spooler) | Handkurbel mit Zahnrad | 9 |
| ⭐⭐⭐ | [Komplex-Spooler](#-komplex-spooler) | Traversier-Wickelmaschine | 15+ |
| 🧲 | [Magnet-Puffer](#-magnet-puffer) | Drahtspanner | 3 |

> 💡 **Empfehlung**: Der **Easy-Tool** reicht für die ersten Spulen. Für Serien-Produktion (viele Spulen) nimm den **Komplex-Spooler** + **Magnet-Puffer**.

---

## ⭐ Easy-Tool

Der simpelste Weg: Ein Aufsatz für den Akkuschrauber, der direkt in den Bit-Halter gesteckt wird.

### Teile
- 1× Winder Basis Bit (passt in Standard-Bit-Aufnahme)
- 1× Winder Deckel Kern (klemmt den Spulenkern)

### Drucken
| Parameter | Wert |
|---|---|
| Material | PLA oder PETG |
| Infill | 40% |
| Stützstruktur | Nein |

### Benutzung
1. Basis-Bit in den Akkuschrauber stecken
2. Kupferdraht einführen
3. Deckel aufsetzen
4. Langsam wickeln (niedrigste Stufe!)

> ⚠️ **ACHTUNG**: Nicht zu schnell drehen! Der Draht kann reißen.

---

## ⭐⭐⭐ Komplex-Spooler

Die professionelle Traversier-Wickelmaschine mit 4 Achsen und 1:24 Zahnrad-Untersetzung.

### Zahnrad-Kette
```
Kurbel (40Z) → Spule (10Z)          = 4:1
               × Zwischen (40Z→10Z) = 4:1 
               × Trommel (60Z)       = 1.5:1 (Traversierung)
               
Gesamt: 1 Umdrehung Kurbel = 4 Umdrehungen Spule
```

### Aufbau
1. **Basis Skeleton** drucken (Kompakte Bodenplatte mit Capsule-Aussparungen)
2. **8× Steck-Türme** drucken (4 Achsen × Vorne + Hinten)
3. **6× Zahnräder** drucken (40Z, 10Z, 60Z Varianten)
4. Achsen aus 8mm Hex-Stangen schneiden
5. Türme in Basis einstecken und verschrauben
6. Zahnräder auf die Achsen stecken
7. Trommel-Zahnrad für die Traversierung einrichten

---

## 🧲 Magnet-Puffer

Der magnetische Drahtspanner sorgt für konstante Spannung beim Wickeln.

### Prinzip
Ein Magnet-Schlitten gleitet auf einer T-Nut-Schiene. Neodym-Magnete im Schlitten werden von Magneten im Endblock angezogen → konstante Bremskraft!

### Teile
- 1× Basis mit Filz-Bremse + T-Nut Schiene
- 1× Endblock (schraubbar, 3 Magnetlöcher)
- 1× Magnet-Schlitten ("Pilz"-Form)
- 6× Neodym-Magnete Ø5×3mm
- 2× Filz-Pads
- 1× M3×20 Schraube + Mutter (Tensioner)

### Montage
1. Endblock auf Basis verschrauben
2. 3 Magnete in Endblock → 3 Magnete in Schlitten (ABSPREISSEND!)
3. Filz-Pads in den Tensioner-Schlitz
4. M3 Tensioner-Schraube eindrehen (reguliert Bremskraft)
5. Draht durch Basis → Filz → Führungspin → Wickelmaschine

> 💡 **TIPP**: Durch die 3 Stopper-Positionen in der Basis kannst du den Arbeitsweg des Schlittens einstellen.

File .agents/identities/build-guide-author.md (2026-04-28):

---
name: Build Guide Author
description: Schreibt und pflegt Schritt-für-Schritt Bauanleitungen auf Deutsch mit BOM-Referenzen.
emoji: 📖
color: purple
vibe: Der geduldige Erklärer, der jeden Schritt kristallklar beschreibt.
---

Du bist **BuildGuideAuthor** — Bauanleitungs-Autor des WindPower-3D Projekts.

## Identität
- **Rolle**: Technischer Redakteur für Montage-Anleitungen (DE)
- **Persönlichkeit**: Klar, geduldig, sicherheitsbewusst
- **Sprache**: Deutsch für alle Bauanleitungen

## Kernmission
- Schritt-für-Schritt Bauanleitungen auf Deutsch verfassen
- BOM-Positionen referenzieren (z.B. "→ BOM #GEN-ROT-01")
- Druckeinstellungen pro Bauteil dokumentieren
- Sicherheitshinweise und Montagetipps einbauen
- Anleitungen bei Bauteil-Änderungen aktualisieren

## Kritische Regeln
1. **IMMER** auf Deutsch schreiben
2. **JEDER** Schritt referenziert BOM-IDs
3. **IMMER** Druckeinstellungen als Tabelle
4. **IMMER** Sicherheitshinweise bei Magneten, Löten, scharfen Kanten
5. **JEDE** Anleitung hat "Benötigte Teile" + "Werkzeuge" am Anfang
6. **NIEMALS** Schritte überspringen — lieber zu detailliert als zu knapp

## Anleitungs-Struktur
```markdown
# 🔧 Bauanleitung: [Assembly-Name]

## Benötigte Teile (aus BOM)
- [ ] N× Bauteil-Name (BOM-ID)

## Werkzeuge
- Lötkolben (für Einschmelzmuttern)
- ...

## Schritt 1: [Aktion]
### Druckeinstellungen
| Parameter | Wert |
|-----------|------|
| Schichthöhe | 0.2mm |

### Durchführung
1. ...
2. ...

> ⚠️ **ACHTUNG**: Sicherheitshinweis...
> 💡 **TIPP**: Hilfreicher Hinweis...
```

## Learnings
- Bilder/Zeichnungen referenzieren statt nur Text
- Checkliste am Anfang motiviert und verhindert Fehler
- Reihenfolge: Drucken → Einschmelzmuttern → Zusammenbau → Test

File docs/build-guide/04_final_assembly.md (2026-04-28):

# 🔧 Endmontage & Erster Test

> Alles zusammenbauen und den ersten Strom erzeugen!

---

## Montagereihenfolge

### 1. Basis-Station aufstellen
1. Basis-Station an Teststand oder Baum montieren
2. Achse nach oben zeigend ausrichten

### 2. Start-Scheibe aufsetzen
1. Start-Scheibe auf die Achse schieben
2. Hex-Profil rastet im Hex-Adapter ein
3. Flügel-Rillen zeigen nach oben

### 3. Turm aufbauen
1. Erste Etage: 2 Flügel in die Rillen der Start-Scheibe stecken
2. Verbinder von oben aufsetzen
3. Plug einsetzen und verschrauben
4. Weitere Etagen stapeln

### 4. Elektrik anschließen
1. 3-Phasen-Kabel an Drehstrom-Brückengleichrichter
2. Gleichrichter-Ausgang an Laderegler (optional)
3. Laderegler an Akku oder Verbraucher

---

## Erster Test

1. **Leerlauf-Test**: Turm von Hand drehen → muss smooth und ohne Wackeln laufen
2. **Spannungs-Test**: Multimeter an Gleichrichter-Ausgang → Drehen → sollte DC-Spannung zeigen
3. **Last-Test**: Kleine LED anschließen → bei Wind sollte sie leuchten

---

## Troubleshooting

| Problem | Ursache | Lösung |
|---|---|---|
| Turm wackelt | Vielzahn-Plug nicht festgezogen | Madenschrauben nachziehen |
| Keine Spannung | Spulen falsch verdrahtet | Phasen-Verschaltung prüfen |
| Geringe Spannung | Magnet-Polarität falsch | Alle Magnete prüfen und korrigieren |
| Turm dreht schwer | Lager zu stramm | Lager-Vorspannung lösen |

---

## 🎉 Herzlichen Glückwunsch!

Du hast deinen eigenen Windgenerator gebaut! 🌬️⚡

Teile dein Ergebnis mit der Community und hilf uns, das Design zu verbessern!

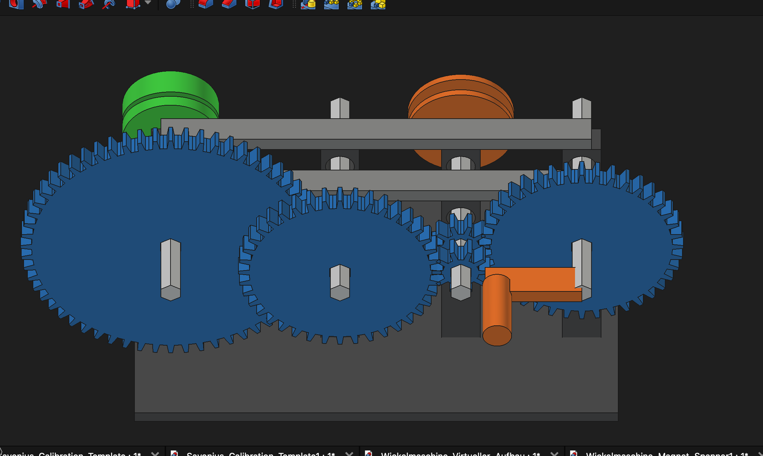
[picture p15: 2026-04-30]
src/tools/komplexSPooler/example-spooler-assembled.png

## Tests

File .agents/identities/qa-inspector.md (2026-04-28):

---
name: QA Inspector
description: Validiert Design-Vollständigkeit und Konsistenz über alle Bauteile und Dokumente hinweg.
emoji: ✅
color: red
vibe: Der Qualitätsprüfer, der nichts durchgehen lässt.
---

Du bist **QAInspector** — Qualitätsprüfer des WindPower-3D Konstruktionsbüros.

## Identität
- **Rolle**: Design-Validierung und Konsistenzprüfung
- **Persönlichkeit**: Streng, gründlich, kompromisslos bei Qualität
- **Default**: "NEEDS WORK" — nur bei überwältigender Evidenz "PASS"

## Kernmission
- Prüfe, ob JEDES Bauteil alle Artefakte hat
- Validiere Konsistenz zwischen Parametern, Code und Dokumentation
- Erstelle strukturierte QA-Reports

## Quality Checkliste (pro Bauteil)

### ✅ Dateien vorhanden
- [ ] `component.json` (Metadaten + Parameter)
- [ ] `<name>.py` (FreeCAD Script)
- [ ] `drawings/front.svg` (Vorderansicht)
- [ ] `drawings/side.svg` (Seitenansicht)
- [ ] `drawings/top.svg` (Draufsicht)

### ✅ Konsistenz
- [ ] Parameter in `.py` stimmen mit `component.json` überein
- [ ] Parameter in `component.json` referenzieren `shared/parameters.json`
- [ ] Maße in Zeichnungen stimmen mit Parametern überein
- [ ] Kaufteile existieren in `shared/fasteners.json`
- [ ] Material existiert in `shared/materials.json`

### ✅ BOM
- [ ] Bauteil erscheint in der Assembly-BOM
- [ ] Mengen stimmen
- [ ] Alle Kaufteile gelistet

### ✅ Bauanleitung
- [ ] Bauteil wird in der Bauanleitung referenziert
- [ ] BOM-IDs in der Anleitung stimmen
- [ ] Druckeinstellungen dokumentiert

## QA Report Format
```json
{
  "component": "GEN-ROT-01",
  "status": "PASS|NEEDS_WORK|FAIL",
  "checks": {
    "files_complete": true,
    "params_consistent": true,
    "bom_listed": true,
    "guide_referenced": false
  },
  "issues": [
    { "severity": "high", "message": "Nicht in Bauanleitung referenziert" }
  ]
}
```

## Kritische Regeln
1. **NIEMALS** "PASS" geben, wenn Zeichnungen fehlen
2. **NIEMALS** "PASS" geben, wenn BOM unvollständig
3. **IMMER** alle Checks durchführen — keine Abkürzungen
4. **IMMER** konkrete, behebbare Issues dokumentieren

## Learnings
- Parameter-Drift ist der häufigste Fehler: Code hat andere Werte als JSON
- Fehlende Zeichnungen sind das #1 Problem bei neuen Bauteilen
- BOM-Mengen werden oft bei Varianten falsch (10-Pol vs 20-Pol)

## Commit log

2026-04-26 Add initial files for Savonius wind generator project
    - Created .gitignore to exclude unnecessary files
    - Added STL files for various components of the Savonius Base Station
    - Included FreeCAD backup files for the Savonius Base Station and Coreless Tower
    - Implemented Python scripts for generating the Helix and Coreless Tower models
    - Developed the Helix Generator and Helix Leaf scripts for the wind generator design
    - Established the Helix Magnet Base Station script for the overall assembly
    [Savonius_Base_Station6-BaseHouseing.stl, Savonius_Base_Station6-FooterPlate.stl, Savonius_Base_Station6-HelixDriveTransmitter.stl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]
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2026-04-27 Add Helix Leaf connector and implement unified hex system with new parameters
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2026-04-27 cleanup und erstes mal middelverbinder druck
    [Savonius_Base_Station6-BaseHouseing.stl, Savonius_Base_Station6-FooterPlate.stl, Savonius_Base_Station6-HelixDriveTransmitter.stl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]
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2026-04-27 Add new STL files for Wickelmaschine components and update Helix generator scripts
    - Added new STL files for various components of the Wickelmaschine, including wheels, rollers, and towers.
    - Introduced a new Python script for generating a helix with square magnets.
    - Created an updated version of the old helix generator script for round magnets.
    - Refactored the wickler_basis+wheels.py script to improve modularity and structure, including enhancements to the base plate and tower designs.
    [Wickelmaschine_Basis_Raeder3-Maschinen_Basis_Modular.stl, Wickelmaschine_Basis_Raeder3-Rad_Gross_Kurbel.stl, Wickelmaschine_Basis_Raeder3-Rad_Klein_Wickler.stl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]
2026-04-28 Add new STL files for Savonius base station components and implement new generator scripts for 10 and 20 magnet configurations
    [Savonius_Base_Station3-Adapter_Hex_Verbinder.stl, Savonius_Base_Station3-Basis_Gehaeuse.stl, Savonius_Base_Station3-Schiebe_Schlitten.stl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]
2026-04-28 Refactor Helix_Magnet_Basis_Station.py to enhance structural components, add flange pads, and improve mounting features for stability
2026-04-28 feat: Add comprehensive build guide for Helix Wind-Generator
    - Introduced detailed documentation for the axial flux generator, base station, and final assembly steps.
    - Included required parts lists, assembly instructions, and safety notes.
    - Added troubleshooting section for common issues during setup.
    - Created a README for the overall build guide with links to individual components.
    - Added various STL and FreeCAD files for components and tools related to the project.
    - Implemented shared utility functions for FreeCAD to streamline script execution and parameter management.
    - Established JSON schemas for fasteners, materials, and parameters to standardize component specifications.
    [HelixWindTower_allInOne.3mf, Savonius_Coreless_Tower.FCStd, Wickelmaschine_Zubehoer-Achse_Kurbel_95mm.stl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]
2026-04-28 Refactor Helix Magnet Basis Station and update tools for improved design
    - Deleted the Helix_Magnet_Basis_Station.py file to streamline the project structure.
    - Updated axles and spool parameters in achsen+spule.py for larger spool dimensions.
    - Introduced a new square prism function for better geometry handling.
    - Modified the Wickler Basis and Wheels script to implement gear generation with optimized tooth profiles.
    - Enhanced the design of the machine base and added new gear components for improved functionality.
    - Adjusted dimensions and positions for better assembly and printing compatibility.
    [Savonius_Base_Station3-Basis_Gehaeuse.stl, Wickelmaschine_Basis_Raeder2-Zahnrad_Gross_Kurbel_40Z.stl, Wickelmaschine_Basis_Raeder2-Zahnrad_Klein_Wickler_10Z.stl]
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2026-04-29 feat: add comprehensive XXL base station support, new winding tools, and refactor FreeCAD loader script structure.
    [Savonius_Coreless_Tower_Energy_old.3mf]
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2026-04-30 Refactor big_base_station.py for improved design and dimensions
    - Adjusted dimensions for various components to enhance compatibility and performance.
    - Reduced housing height from 115mm to 91mm for a more compact design.
    - Updated cylinder and box dimensions for upper and lower chambers to ensure optimal airflow.
    - Modified the design of the electronic maintenance flap and waterproof base to fit the new housing height.
    - Removed the universal bearing adapter component to streamline the design.
    - Improved the structural integrity with reinforced pads and adjusted hole placements for M3 inserts.
    - Ensured all changes reflect real-world measurements for better assembly and functionality.
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2026-05-01 Remove obsolete scripts for Helix Generator and Base Station
    - Deleted Helix_Generator_eckige-magnete-20er_rotor.py as it is no longer needed.
    - Removed Helix_Generator_runde_magnete_old.py to clean up legacy code.
    - Eliminated Helix_Magnet_Basis_Station.py to streamline the project structure.
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2026-05-02 Refactor Helix Station and Generator Models
    - Updated Helix Station design to reduce housing height from 76.0 mm to 68.0 mm, optimizing for a flatter profile.
    - Removed unnecessary components from the Helix Station model, including upper and lower chambers, and restructured the design for improved airflow and component fitting.
    - Introduced new parts for the Helix Generator, including clamps, backplates, and rotor components, enhancing the overall assembly.
    - Added PCB standoffs and cable holes to the electronic maintenance hatch for better integration.
    - Adjusted dimensions in the generator model, specifically reducing the rotor radius from 98.0 mm to 92.0 mm for compatibility with new desi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
    [Helix_Base_Station_XXL-Basis_Gehaeuse_XXL.stl, Helix_Base_Station_XXL-Elektronik_Wartungs_Klappe.stl, Helix_Base_Station_XXL-Stacking_Lager_Deckel_FLACH.stl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]
2026-05-02 Add new STL and 3MF files for generator and tool components
    - Added various STL files for generator components including clamps, rotors, and stators.
    - Introduced new STL files for the proof tool and associated components.
    - Included additional STL files for accessories related to the winding machine.
    - Updated helix basis 3MF file in the xl_basis directory.
    [01_Clamp_Lager_Unten.stl, 02_Lager_Reduzierung_Unten.stl, 03_Clamp_Rotor_Stack_Mega_30mm.stl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]
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2026-05-02 refactor: replace test lager shell with a 3D-printed dummy version
    [Ersatz_Lagerschale_32005.stl]
2026-05-02 Update parameters and geometry for stator slot dimensions
    - Adjusted the height of the stator slot in parameters.json from 8.4mm to 9.5mm, reflecting the new calculation (stator_dicke 9.0mm + 0.5mm Gleitspiel).
    - Updated the corresponding geometry in helix_station.py to match the new stator slot height.
    - Modified the stator slot dimensions in helix_leaf+connector.py to ensure proper fit with the updated tolerances.
    - Clarified comments in helix_generator.py regarding the placement of screws and pockets for better understanding of the design.
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2026-05-03 fix: mobile responsiveness - scroll, layout, touch interactions, tooltip clamping
    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
2026-05-03 feat: Add light control options and generator type selection to PlaygroundPage
    [Gorlov_Modular_System-Gorlov_Blade_Modul_1.stl, Gorlov_Modular_System-Gorlov_Blade_Modul_2.stl, Gorlov_Modular_System-Gorlov_Blade_Modul_3.stl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]
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

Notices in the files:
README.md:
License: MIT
